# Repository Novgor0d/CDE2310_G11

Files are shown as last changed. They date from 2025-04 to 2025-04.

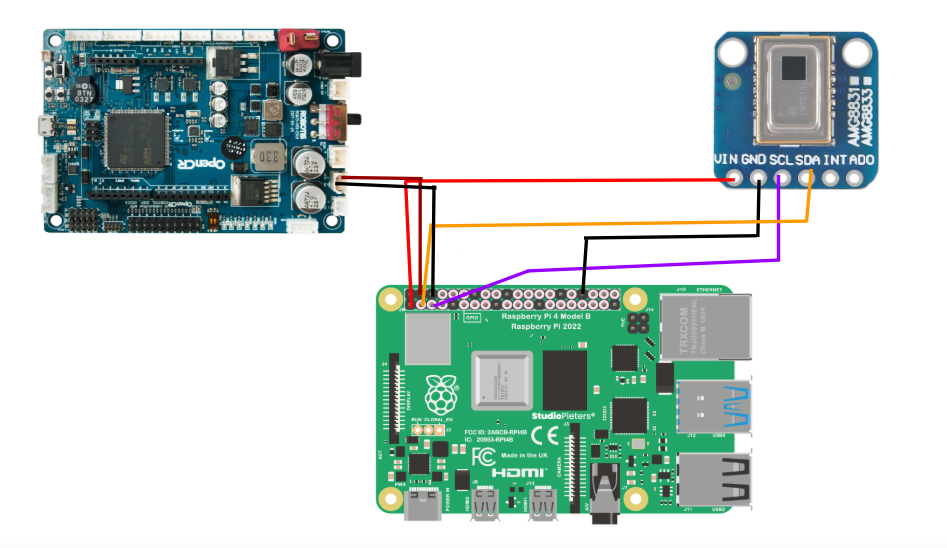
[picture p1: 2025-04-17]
Electrical Subsystem/Circuit_Diagram_AMG8833.png

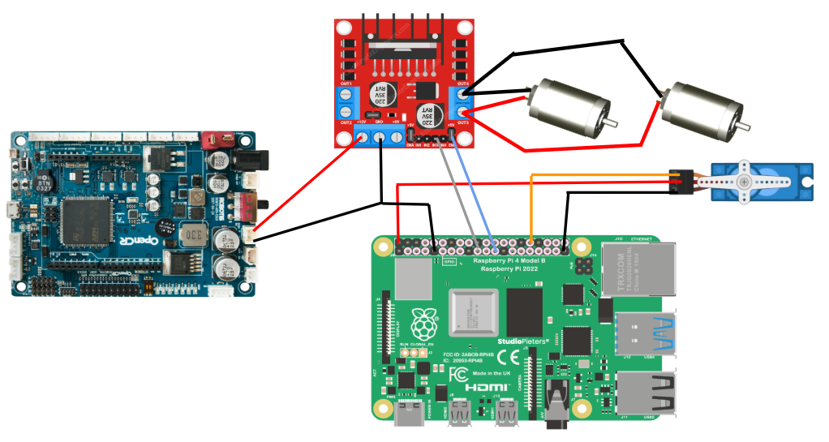
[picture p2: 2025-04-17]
Electrical Subsystem/Circuit_Diagram_Flywheel.png

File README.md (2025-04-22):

##  Project Overview

This repository contains the project details for **CDE2310 AY24/25**.

The contents within the following folders can be used to **replicate the project**:
- `Software`
- `Electrical Subsystem`
- `Mechanical Subsystem`

The **mission details**, along with all **conditions and constraints**, are provided in the `Requirement Specifications` document.
The **User Manual** and **Testing Documentation** contain detailed information about the **robot's design** and **how its functionality can be tested** prior to mission execution.

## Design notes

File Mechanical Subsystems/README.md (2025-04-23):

## Mechanical Subsystem

This document outlines the **complete design, fabrication, and assembly process** for our autonomous ping pong ball launcher mounted on the TurtleBot3 Burger. The system is designed to detect a heat source, navigate autonomously, and fire a ping pong ball vertically using a dual-flywheel launch mechanism. It includes detailed breakdowns of parts, fabrication methods, performance calculations, and step-by-step assembly instructions to ensure clarity and reproducibility.

**_All the items that have been mentioned in this document refer directly to the file name._**

## Files and their description under Mechananical Subsystems

**Reload Tube Folder:**
- Joint2: attatches 18cm pipe to the launcher 
- Joint: attatches 15cm pipe to the 18cm pipe 
- Reload Tubes assem: the entire assembly file with pipes and joints
- Tube 18cm: attaches to the launcher directly using a press-fit joint
- Tube 15cm
- Tubes holder: Attaches to turtlebot for holding the 18cm tube 

**Launcher Folder:**
- DC motor & servo platform: Attaches DC motors and servo to the turtlebot 
- DC motor gear: 30 teeth 
- JGB37-520 left assem: assembly file with motor
- JGB37-520 left bracket  
- JGB37-520 right assem: assembly file with motor  
- JGB37-520 right bracket  
- SG90 servo assem (rack and pinion)  
- SG90 servo bracket (rack and pinion)  
- ball platform - Holds the ball and has the rack (15 teeth)
- flywheel - File has the flywheel plus the gear (12 teeth) 
- launcher + reload tubes assem  
- launcher  
- pinion gear (rack and pinion): 29 teeth

**Turtlebot Assembly files:**
- Turtlebot Assembly:- Base turtlebot burger
- Turtlebot & Launcher Mechanism Assembly: Final Turtlebot Burger assembly with the launcher and the ball feeder system.

## 3D Printing
CAD files can be saved as STL files to 3D Print.

**Parts to be printed:**
- Launcher 
- JGB37-520 left bracket
- JGB37-520 right bracket  
- SG90 Servo Bracket 
- Ball Platform
- Joint 2
- Joint
- Tubes Holder
- 2X Flywheel (with integrated gear teeth)
- SG90 servo Bracket (heat sensor)

**Specifications for 3D Printing:**
- Infill: 15%
- Material: PLA 

## Laser Cut:
Using a 5mm acrylic sheet the following needs to be laser cut

_Parts to be Laser cut:_
- 2X DC Motor gear 
- Pinion Gear 
- DC Motor and Servo Platform

## Assembly Plan

**Assembly Step 1: SG90 Servo + Heat Sensor Mounting**
- Mount the SG90 servo to the front of the second level using M4×15 screws.
- Attach the sensor bracket to the servo horn using M2×10 screws.
- Fix the AMG8833 heat sensor onto the bracket using M2×10 screws.

**Assembly Step 2: Mount Pinion and Attach Servo Platform**
- Attach the pinion gear to the output shaft of the SG90 servo.
- Mount the servo onto the platform bracket using M2×15 screws.
- Fix the entire servo and motor platform onto the top layer using M3×15 screws through the holes aligned with the hex standoffs.

**Assembly Step 3: Mount Flywheel Launcher Assembly**
- Mount the JGB37-520 motors onto the launcher platform using M2×15 and M4×15 screws.
- Attach the 30-tooth motor gear to the motor shaft.
- Wrap each flywheel with 8 rubber bands each to improve traction.
- Slide the 3D printed shaft through the flywheel and secure it so the 12-tooth flywheel gear meshes precisely with the motor gear (gear ratio 5:2).
- Insert the ball holder platform from above
- Extend the third platform layer by attaching M3×20 hex standoffs to the existing mounting holes.
- Secure the entire launcher assembly onto the TurtleBot chassis using M4X15 and M3X15 screws through the designated mounting holes, aligning the pinion (29T) on the servo with the rack (15T) for accurate engagement.

**Assembly Step 4: Ball Feeder Pipe Installation**
- Mount the pipe support bracket to the TurtleBot platform using M2×20 screws.
- Press-fit the 15 cm PVC pipe into the 3D printed 90° elbow joint.
- Connect the 15 cm pipe to the 18 cm PVC pipe using the same elbow joint.
- Press-fit the other end of the 18 cm pipe into the 3D printed joint2,
- Press-fit joint2 onto the launcher housing and finally, rest the assembled tube system onto the tube holder.

## Launcher Calculations 

**Specifications & Assumptions:**
- Mass of Ping Pong Ball: 2.7 g (0.0027 kg)
- Target Launch Height: 1.5 m
- Flywheel Diameter: 5 cm (0.025 m radius)
- Motor Used: JGB37-520 (nominal no-load speed ~960 RPM)
- Gear Ratio: 30:12 (2.5× step-up)

**Required Launch Velocity:**
v = √(2gh) = √(2 × 9.81 × 1.5) ≈ 5.42 m/s

**Required Flywheel RPM:**
ω = v / r = 5.42 / 0.025 = 216.8 rad/s
RPM = (216.8 × 60) / (2π) ≈ 2072 RPM

**Achieved Flywheel RPM:**
With gear ratio of 2.5× (30 teeth : 12 teeth):
Achieved RPM = 960 RPM (motor) × 2.5 (gear ratio) = 2400 RPM

Our flywheel system achieves an RPM of 2400, which exceeds the required 2072 RPM. This confirms our system can successfully launch the ping pong ball to at least 1.5 meters vertically, satisfying the project requirements  with a performance buffer that accounts for real-world factors such as air resistance and energy losses from friction.

## Mechanical and Assembly Recommendations
- Ensure motor shafts and flywheels are securely fastened to prevent slippage at high RPMs.
- Align gears and flywheels properly to minimize vibration during operation.
- Test with gradual motor ramp-up to check for imbalance or resonance.
- Ensure the PVC ball guide path has minimal friction and doesn’t interfere with launch direction.

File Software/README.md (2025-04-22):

# **Thermal Detection and Autonomous Exploration System**
## **Overview**
This repository contains the software framework for a robotic system capable of detecting thermal sources while performing autonomous exploration of an unknown environment. The system is built on ROS2 and meant for deployement on Raspberry Pi. It maps the surroundings using SLAM, detects heat signatures, and deploys a flare mechanism.

## **Key Features**
- **Autonomous frontier-based exploration:** Uses a frontier exploration algorithm to autonomously navigate towards unexplored regions.
- **Thermal Source Detection:** Detects heat sources based on certain temperature thresholds.
- **Motorized flare deployment:** Fires a flare to indicate successful detection of a heat source, using a flywheel and servo-based system.
- **Data Logging**: Provides detailed logging of system status, sensor data, and actions for debugging and performance monitoring.
- **Full ROS2 Humble compatibility**

## **System Architecture**
The software stack is divided across two platforms:
  - **Remote PC (Main Control Node):** Runs SLAM, Nav2 Stack, RViz visualisation, and the exploration node.
  - **Raspberry Pi (Onboard Robot):** Handles robot bring-up, thermal sensing, and flare deployment mechanisms.
  
## **Prerequisites**
- Ubuntu 22.04 (recommended)
- ROS2 Humble
- ROS2 Packages: nav_msgs, geometry_msgs, action_msgs

  [( Install ROS2 packages and Turtlebot3 here )](https://emanual.robotis.com/docs/en/platform/turtlebot3/sbc_setup/#sbc-setup)
  
  Add the following line to the `.bashrc` file in the root directory of the Remote PC and RPi
   ```bash
   export TURTLEBOT3_MODEL=burger
    ```
  Reload the `.bashrc` file
     ```bash
   source ~/.bashrc
    ```

- Python 3.10+
- Python libraries:
  - `numpy`  
    Install with:  
    ```bash
    pip install numpy
    ```
  - `adafruit-circuitpython-amg88xx`  
    For using amg8833 sensor with Raspberry Pi. Install with:  
    ```bash
    pip install adafruit-circuitpython-amg88xx
    ```
  - `adafruit-blinka`  
    Required for `busio` and `board` on Raspberry Pi. Install with:  
    ```bash
    pip install adafruit-blinka
    ```
## **Installation and Setup**
1. **Create the ROS2 workspace:**
```bash
mkdir -p ~/ros2_ws/src
```
2. **Clone the repository:**

  (On Remote PC)
```bash
cd ~/ros2_ws/src
git clone https://github.com/Novgor0d/CDE2310_G11.git
cd CDE2310_G11/Software/src
cp -r * ~/ros2_ws/src/
rm -rf ~/ros2_ws/src/CDE2310_G11
# Copy the 'src' directory from the local machine's ros2_ws to the Raspberry Pi's ros2_ws/src directory
scp -r ~/ros2_ws/src pi@rpi_ip_address:/home/pi/ros2_ws/src
# Replace the username and ip address with your RPi's
rm -rf ~/ros2_ws/src/thermal_explorer
rm -rf ~/ros2_ws/src/fire_flare
```
  (On RPi)
```bash
# These commands are to be run after the 'src' directory has been copied over from the remote PC to the RPi
cd ~/ros2_ws/src
rm -rf ~/ros2_ws/src/custom_explorer
rm -rf ~/ros2_ws/src/robot_config
```
The rm commands are used to clean up the workspace by removing nested or redundant directories after extracting the necessary packages for remote PC and RPi, ensuring a flat and organized structure in ~/ros2_ws/src.

3. **Install dependencies and build the workspace:**
```bash
cd ~/ros2_ws
rosdep install --from-paths src --ignore-src -r -y
colcon build
```
4. **Source the workspace:**
```bash
source install/setup.bash
```
## **Running the System**
### ***On Remote PC:***
Run the following commands in separate terminal windows:
1. **Start RViz2 for visualization:**
```bash
ros2 run rviz2 rviz2 -d $(ros2 pkg prefix nav2_bringup)/share/nav2_bringup/rviz/nav2_default_view.rviz
```
2. **Launch SLAM:**
```bash
ros2 launch slam_toolbox online_async_launch.py
```
3. **Use Custom Navigation Parameters:**
   
This system uses a customized nav2_params.yaml file located at: robot_config/config/nav2_params.yaml
```bash
ros2 launch robot_config nav2_launch.py
```
This step ensures that all Nav2 nodes (e.g., planner, controller, recovery behaviours) run with the tuned parameters specific to this project. These parameters can be adjusted as per requirement.

4. **Run the custom exploration node:**
```bash
ros2 run custom_explorer explorer
```
### **On Raspberry Pi:**
Run the following commands in separate terminal windows:
1. **Launch TurtleBot3 bringup:**
```bash
ros2 launch turtlebot3_bringup robot.launch.py
```
2. **Start the thermal detection node:**
```bash
ros2 run thermal_explorer thermal
```
3. **Run the flare firing mechanism:**
```bash
ros2 run fire_flare motor
```
## **Simulating in Gazebo:**
To simulate the navigation in a virtual environment, run the following commands in separate terminals:
1. **Launch the TurtleBot3 in a Gazebo simulation world:**
```bash
ros2 launch turtlebot3_gazebo turtlebot3_world.launch.py
```
2. **Launch SLAM with simulation time enabled:**
```bash
ros2 launch slam_toolbox online_async_launch.py use_sim_time:=True
```
3. **Launch Nav2 stack with simulation time enabled:**
```bash
ros2 launch robot_config nav2_launch.py use_sim_time:=True
```
4. **Run the custom exploration node in the simulation:**
```bash
ros2 run custom_explorer explorer
```

## **System Functionality**
### **Thermal Detection and Flare Firing**
Upon initialization, the system continuously scans the environment using the thermal sensor. When a heat source (e.g., fire) is detected, the robot navigates towards the source and fires a flare to indicate the detection. The detection and flare firing are performed based on a predefined temperature threshold, which can be configured to suit various use cases.

### **Autonomous Exploration**
The system employs a frontier exploration algorithm that identifies unexplored areas (frontiers) in the environment. The robot autonomously navigates towards these regions to gather more data, expanding its knowledge of the environment. The system dynamically switches between frontier-based exploration and random exploration after specified time intervals.

### **ROS2 Communication**
The system utilizes ROS2 for communication between the various components:

**Published Topics:**
  - /fire_flare ([Bool]): Indicates when the robot detects a thermal source and fires a flare.
  - /cmd_vel ([geometry_msgs/msg/Twist]): Command velocity for controlling robot movement.
  - /goal_pose ([geometry_msgs/msg/PoseStamped]): The target position for the robot (e.g., towards a detected heat source or frontier).

**Subscribed Topics:**
   - /odom ([nav_msgs/msg/Odometry]): Odometry data used for robot localization.
   - /map ([nav_msgs/msg/OccupancyGrid]): The map of the environment for exploration and frontier detection.

## Testing and Validation
The system has been tested both in simulated environments (Gazebo) and with real-world hardware. The modular nature of the system ensures that individual components can be tested in isolation for reliability.

The folder **/Test** contains verification scripts for hardware-level functionality of the thermal detection and flare deployment system used in the project.

### **Contents**

**AMG8833_test.py**
- Sweeps a servo across predefined angles.
- Uses the AMG8833 thermal camera to detect heat signatures above a defined threshold.
- if a high heat count is detected, triggers a flare firing sequence by executing Motor_Test.py

**Motor_Test.py**
- Activates a flywheel mechanism and sequentially fires three flares using a servo reload action.
- Includes controlled delays for flywheel spin-up and reload timing.

**servo_reset.py**
- Simple utility script to reset the servo to a neutral (0-degree) position after firing or testing.

### Usage

Ensure you have the necessary hardware connected (thermal sensor, servo, flywheel mechanism), then run the scripts on RPi using
```python
python3 [file_name].py
```

## References
This project was developed with guidance and inspiration from the following sources:
  - [Nav2 Documentation](https://docs.nav2.org/)
  - [Automatic Addison – ROS 2 Navigation Tuning Guide (Nav2)](https://automaticaddison.com/ros-2-navigation-tuning-guide-nav2/)
  - [AutoFrontierSearch (ROS2 - Humble)](https://github.com/Nyanziba/AutoFrontierSearch_ros2-humble/tree/main) – Frontier exploration logic adapted and modified for our use.

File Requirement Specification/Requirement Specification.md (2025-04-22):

#  IR-Heat Detection & Projectile Launcher System for TurtleBot3 Burger (Raspberry Pi 4)

##  Mission Objective

Design and build an **IR (heat) detection module** with an integrated **projectile launcher** for a **TurtleBot3 Burger** running on **Raspberry Pi 4**, capable of completing the following tasks within a single mission:

---

##  Maze Navigation Requirements

1. The TurtleBot must **autonomously navigate a maze** no larger than **5m × 5m**.
2. Maze walls are under **1 meter** in height.

---

##  IR Detection Objectives

1. Within the maze, the robot must locate a **designated heat signature zone**, marked by an **IR-lamp** in an enclosed area that is **randomly placed**.
2. The TurtleBot must also identify **three "Target" objects** (biscuit tins), each with an **infrared heat signature ("Hot target")**.
3. Each hot target has a **vertical positional marker** placed **1.5m above** it.

---

##  Launching Requirements

- The robot must:
  - **Detect** the hot target.
  - **Orient** its position accordingly.
  - **Aim and fire** at the vertical positional marker.
  - Launch a **minimum of 3 ping pong balls** in the following **timing pattern**:  
    **2s → 4s → 2s** intervals between shots.

---

##  Conditions & Constraints

1. All targets are placed **on the floor**.
2. There is **only one elevation zone** (non-critical) located in the **bonus zone**.
3. The projectile must be a **standard-sized ping pong ball**.
4. The **terminal height of the projectile must exceed the height of the maze walls**.
5. The **ping pong ball must not hit the wall or ceiling** of the surrounding room.

---

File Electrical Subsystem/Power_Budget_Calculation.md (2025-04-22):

##  Power Budget Calculations

### **Assumptions**
- **Battery efficiency**: 80%
- **Boot-up time**: 20 seconds  
- **Stand-by time**: 50 seconds  
- **Operation time**: 30 seconds

---

### **Calculation**
(8.4 × 20) + (5.9 × 50) + (13 × 30) + (10.22 × T) = 11.1 × 1.8 × 3600 × 0.8 => T = 92.3 minutes

This means after one complete charge, the **TurtleBot** is expected to run for approximately **92.3 minutes**.

---

**_Note: Please refer to `Power_Budget_Table.png` for the power distribution of each component, which has been used in the above calculations._**

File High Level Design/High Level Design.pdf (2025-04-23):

## High Level Design

Scope:
The robot is equipped to navigate through the maze, detect heat sources and shoot ping-pong balls upon detection, with a time interval of 2s-4s-2s.

Architecture Diagram:
The following diagram illustrates how the various components of the system interact with each other.

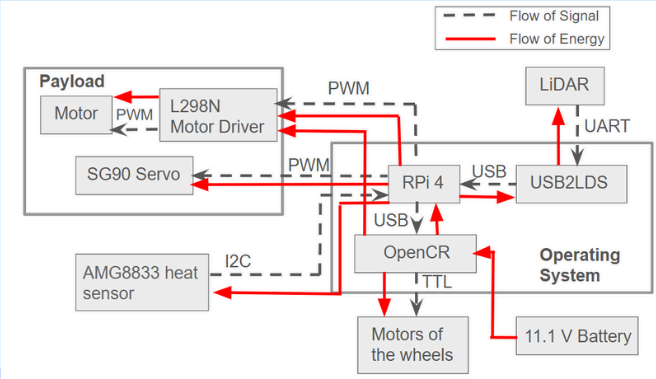
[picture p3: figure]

Component Description:

Item No. | Qty | Part Name
1 | 1 | S90 servo for heat sensor
2 | 1 | AMG8833 sensor
3 | 1 | Ball holder
4 | 2 | Flywheel motor
5 | 2 | Flywheel
6 | 1 | S90 servo for rack and pinion
7 | 1 | Rack and pinion
8 | 1 | Pipe support
9 | 1 | Sensor servo holder
10 | 1 | Acrylic Holder for Launcher
11 | 1 | Weight
12 | 1 | Turtlebot3 burger

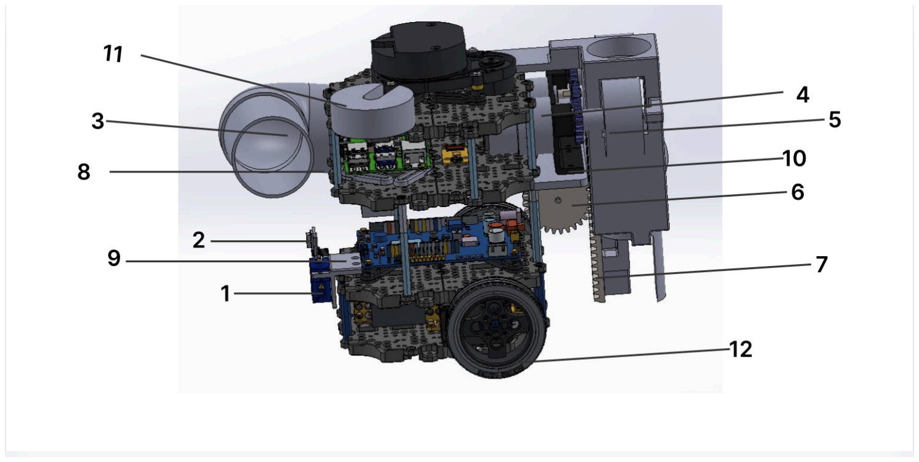
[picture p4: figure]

+

The map created by the lidar along with the odometry reading helps in updating the local and global costmap, along with giving the position of the robot on the map. The pipes are used to store the ping-pong balls. The AMG8833 heat sensor provides a 8x8 array of temperatures, which is used to scan for heat sources. Upon detection of heat sources, the rack and pinion along with the flywheel is activated, which shoots the ping-pong balls. The weight is used to balance out the weight of the motors and launcher, on the other side of the bot.

Data/Control Flow:
The flowchart below shows the logic diagram for heat detection:

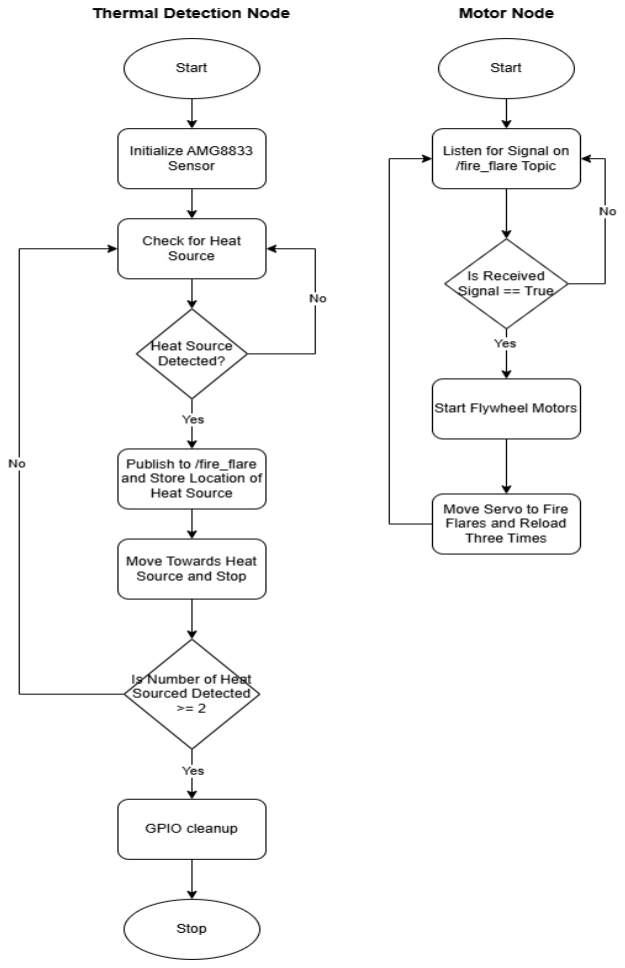
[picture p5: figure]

Fig: Logic diagram for heat detection

The flowchart below represent the logic diagram for navigation:

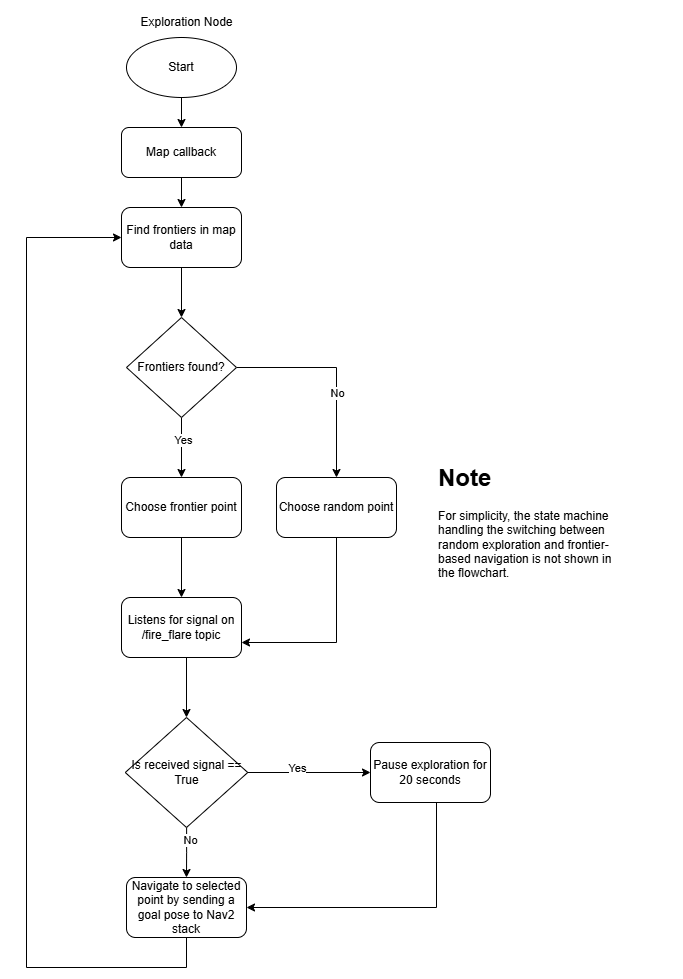
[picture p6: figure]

Fig: Logic diagram for navigation.

Design Consideration:

| List | Specifications | Notes
Turtlebot | Dimensions (mm) (LxWxH) | Turtlebot3 & Launcher: 293x262x212
| Weight (kg) | Launcher: 0.924 Turtlebot: 1.51 Counter-weight: 0.2 Total weight: 2.634
| Wheel Base (mm) | 80.66 | From center of DYNAMIXEL to the center of ball caster
| DC Motor | 2x JGB37-520
| Servo Motor | 2x SG90
Payload | Dimensions (mm) (LxWxH) | 40 x 40 x 40 | Ping Pong Ball
| Weight (kg) | Ping Pong: 0.0027 Total: 0.0243 | 9 Ping Pong Ball
System | Battery Capacity | 1800 mAh
| Expected Operating Time | 92.3 min
| Communication Interface | GPIO,PWM,I2C,UART,USB, TTL, TCP

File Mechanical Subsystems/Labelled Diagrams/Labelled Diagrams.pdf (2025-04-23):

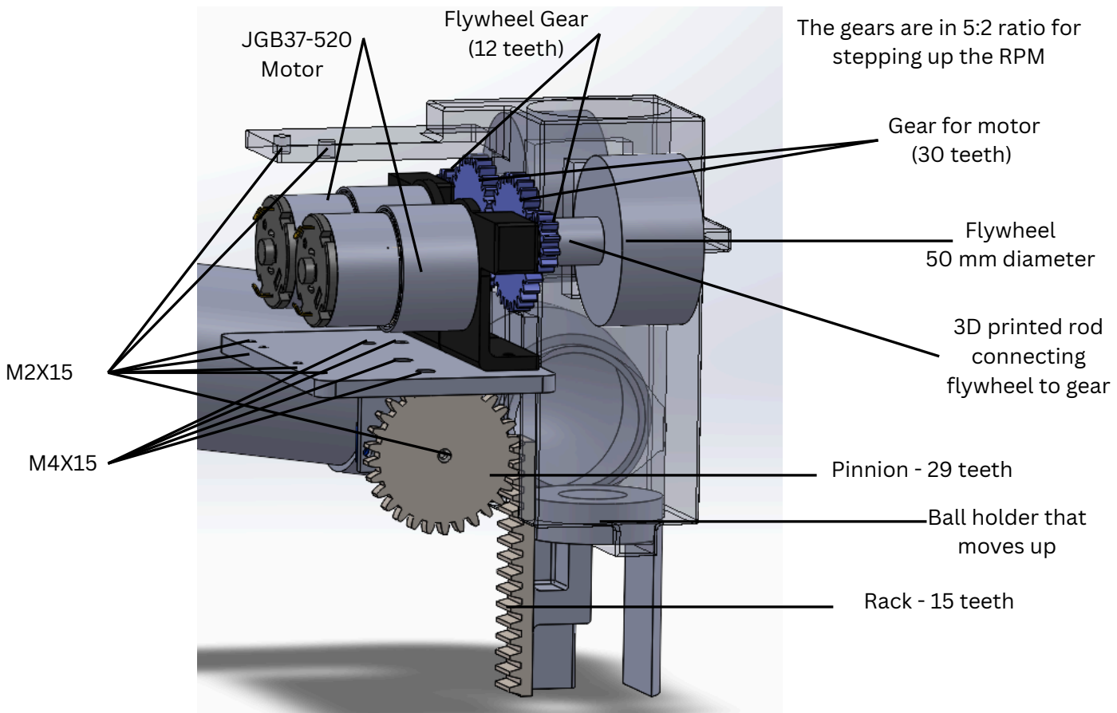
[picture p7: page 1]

Pinnion - 29 teeth

Rack - 15 teeth

Flywheel
50 mm diameter

JGB37-520
Motor

M2X15

M4X15

Gear for motor
(30 teeth)

Ball holder that
moves up

3D printed rod
connecting
flywheel to gear

Flywheel Gear
(12 teeth)

The gears are in 5:2 ratio for stepping up the RPM

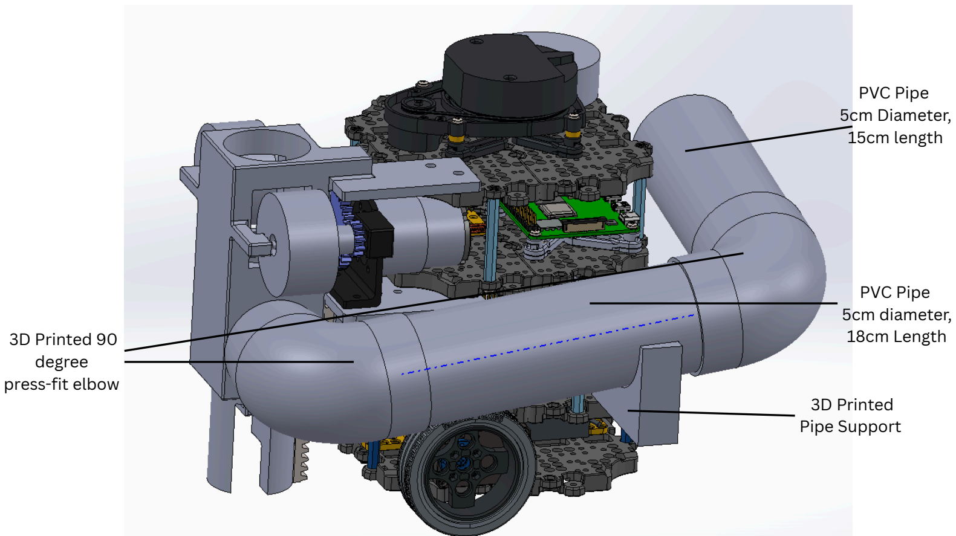
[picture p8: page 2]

PVC Pipe
5cm diameter,
18cm Length

3D Prin

ted
Pipe Support

3D Prin

ted 90
degree
press-fit elbo

w

PVC Pipe
5cm Diameter,
15cm length

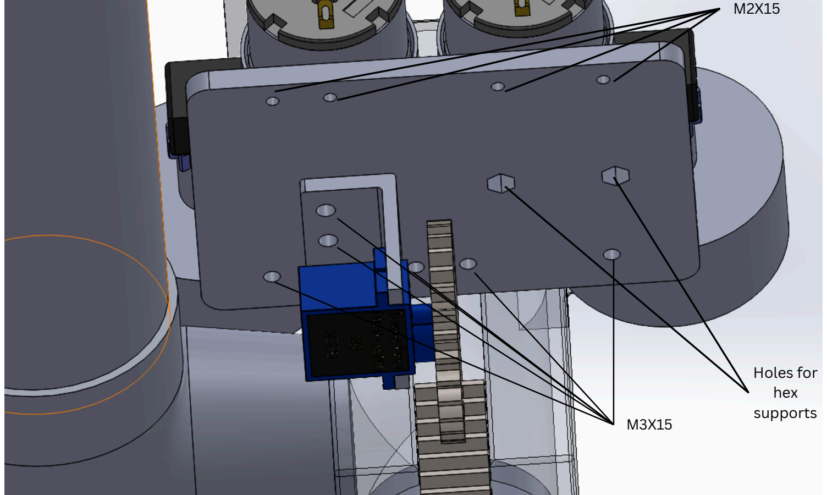
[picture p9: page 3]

M2X15

Holes for
hex
supports M3X15

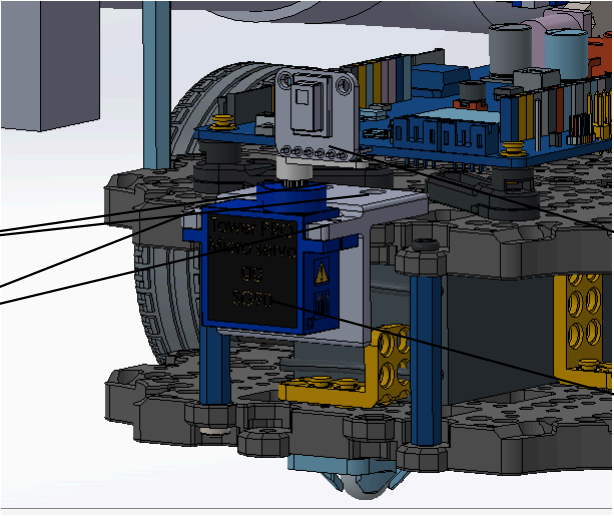
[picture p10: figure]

SG90 Serv

o

AMG8833
Heat Sensor

M4X15

M2X10

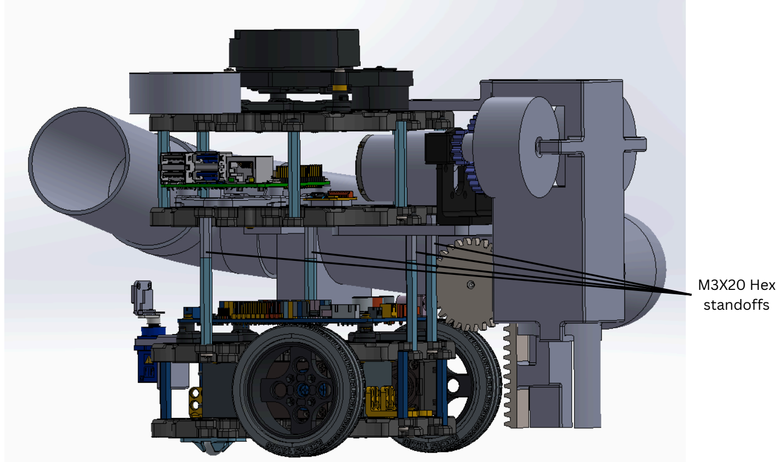
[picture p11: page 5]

M3X20 Hex
standoffs

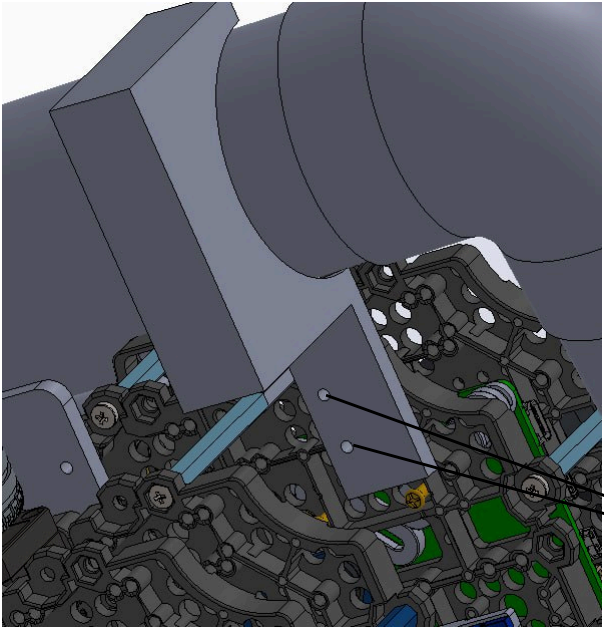
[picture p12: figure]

M2X20

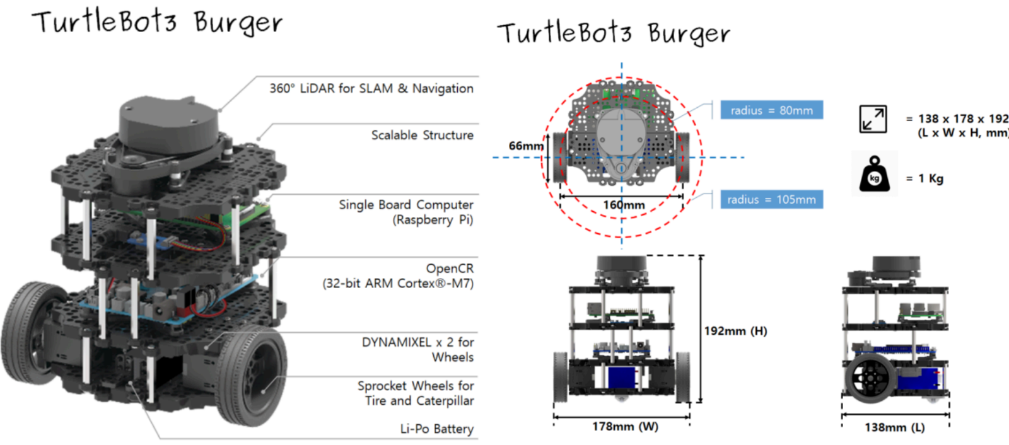
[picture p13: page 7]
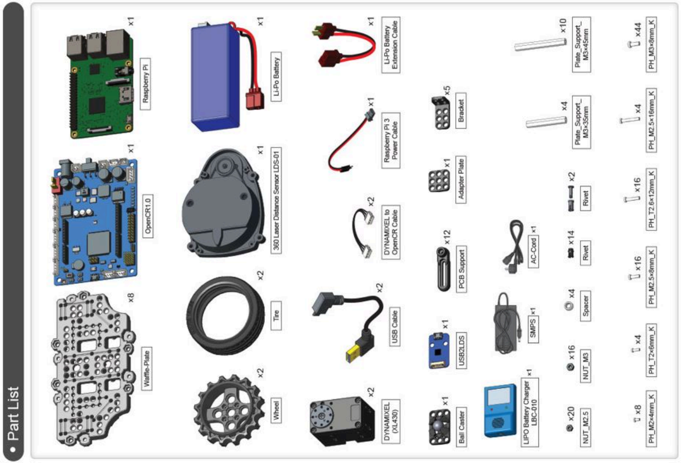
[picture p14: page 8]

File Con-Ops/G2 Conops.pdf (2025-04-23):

Problem Description
The mission involves designing and building a TurtleBot3 Burger system equipped with a IR (heat) detection module and a projectile launcher capable of autonomously navigating a 5m x 5m maze with walls under 1m in height. Within the maze, the robot must locate a designated heat signature zone marked by an IR lamp enclosed in a randomly placed space and identify three "hot targets" — biscuit tins emitting infrared heat and marked with vertical position indicators 1.5m above them. Upon locating a hot target, the robot must orient itself, aim, and fire three ping pong balls at the vertical marker in a specified 2s–4s–2s timing

sequence.

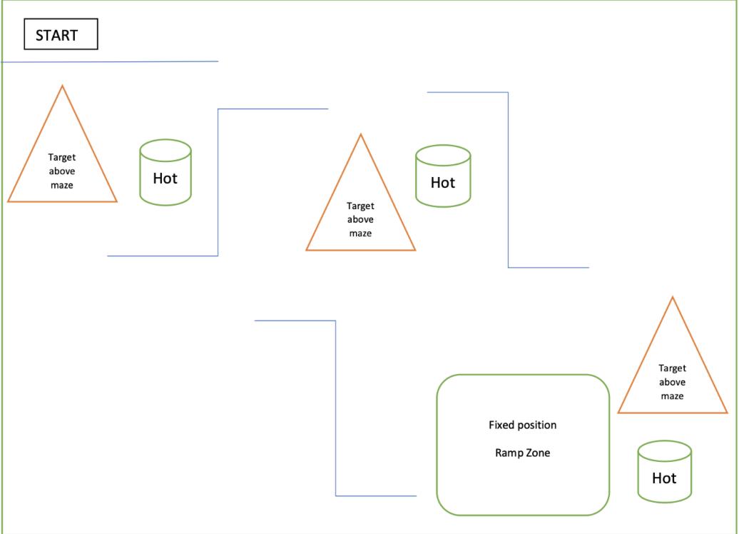
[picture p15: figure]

Figure 1: Mission Layout

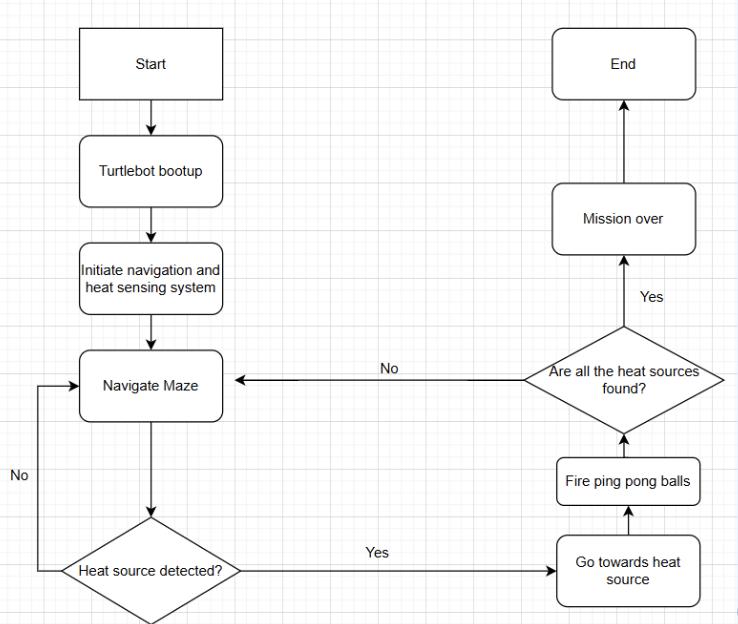
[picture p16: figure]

Figure 2: General Con-Ops Overview

Stakeholder Requirements | Project Deliverables
Traverse map autonomously | Implement mapping techniques to generate real time map of maze
Avoid obstacles | Develop capability for obstacle avoidance and navigation
Detect Heat source | Detect heat readings and trigger launcher when above threshold
Fire Flares above 1m | Generate enough power to fire ball above 1m
Fire at interval | Incorporate firing timing at 2-4-2 intervals
Stakeholder Requirements | Functional Requirements
Traverse map autonomously | Using SLAM incorporate frontier exploration and path planning algorithm to continuously update and refine map during exploration
Avoid obstacles | Utilise sensors and lidar to detect obstacles and navigate around them

Detect Heat source | Using heat sensor set threshold and create code such that when threshold is hit, launch mechanism triggers
Fire Flares above 1m | Use flywheel mechanism ,rack and pinion system to load balls into flywheel mechanism
Fire at interval | Using servo adjust speed at which balls are loaded into the flywheel
Constraints | Description
Cost | 80 Dollar budget
Power | Operate within constraints of power source
Sensor | Limited by cost and availability
Processing power and memory | Limited due to Rpi, affects algorithm efficiency
Size | Fit within walls and passages of the maze

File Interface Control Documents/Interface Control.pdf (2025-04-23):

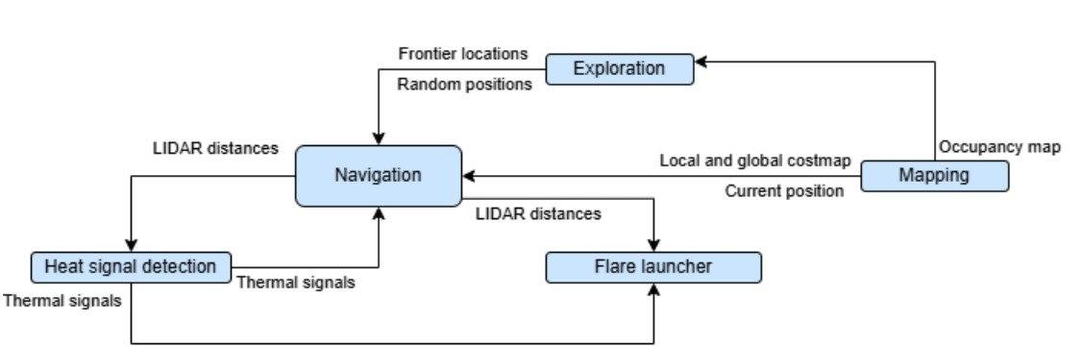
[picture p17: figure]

Interface Control Flowchart

The flowchart illustrates the software architecture and data flow in the autonomous Turtlebot system designed for IR-based search and targeting. The core of the system is the Navigation module, which receives frontier locations or random positions from the Exploration module to guide the robot through the environment. The Mapping module continuously updates the local and global costmap and provides the current position based on the occupancy map, feeding this information to the Navigation module for real-time decision-making. Simultaneously, LiDAR distances are used by both the Navigation module and the Heat Signal Detection unit to localize and identify thermal targets. Upon detecting valid thermal signals, the Heat Signal Detection module relays data to the Flare Launcher, which uses both thermal and LiDAR inputs to determine when and where to launch a flare. This integrated loop allows for autonomous mapping, exploration, and accurate response to heat-based targets within a complex maze environment.

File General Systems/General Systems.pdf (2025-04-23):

Autonomous Navigation – SLAM, Frontier Exploration & A* Path Planning

At the core of the robot’s autonomous navigation system is a 2D LiDAR sensor, which continuously scans its surroundings to generate a real-time occupancy grid map via SLAM (Simultaneous Localization and Mapping). This dynamic map serves as the foundation for both exploration and navigation. The robot employs a frontier-based exploration strategy, which identifies boundaries between explored and unexplored space ("frontiers")and prioritizes movement toward these regions to maximize map coverage efficiently. Once a frontier goal is selected, the A* path planning algorithm is used to compute an optimal route through free space, balancing path length and obstacle avoidance. This high-level planner interfaces with local control modules to generate velocity commands, enabling the robot to maneuver safely around static walls and dynamic obstacles while progressing toward its mission objectives. The integration of SLAM, frontier detection, and A* ensures reliable, efficient, and intelligent navigation within unknown and complex maze environments.

Launcher Mechanism – Flywheel System

This system operates by rapidly spinning a pair of opposing wheels using JGB37-250 motors, generating sufficient tangential velocity to propel lightweight projectiles such as ping pong balls. When a projectile is fed into the flywheel gap, frictional contact with the rotating surfaces accelerates it forward at high speeds.We make use of a gear train to increase RPM with the bigger gear connected to the motor and the smaller gear connected to the flywheel axle. This is paired together with our ball loading system to create our flare mechanism.

Rack and Pinion - Ball Loading System

To support automated and repeatable firing, the robot integrates a rack and pinion-based loading mechanism. This system uses a linear actuator where rotational motion from a servo-driven pinion gear is converted into linear displacement of the rack. Each stroke of the rack pushes a single projectile from a pipe into the flywheel launching chamber. This mechanical design ensures consistent alignment and loading of the projectile, minimizing jams while enabling controlled reloading cycles synchronized with the firing sequence. The servo timing was adjusted using code to ensure it loads the balls at 2-4-2 intervals. The pipe rests on a pipe holder and the pipe is at an angle such that the gravitational force causes the balls to roll into the holding area before it is fed into the flywheel.

Heat Detection

The AMG8833 heat sensor creates an 8x8 array of temperatures. When the temperature value and temperature count exceeds a threshold, the launching mechanism is activated.

Power Consumption, Operation time and battery specification

Battery specification: 11.1V, 1800 mAh
Total time for which the system can operate: 92.3 min

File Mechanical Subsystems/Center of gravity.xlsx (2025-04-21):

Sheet: Turtlebot
Part Name |  | CG Position (mm) |  |  | remarks
 | mass (g) | x | y | z
Left wheel | 83.5 | 32.77 | 20.25 | 88.99
Right Wheel | 83.5 | 36.77 | 20.25 | -67.45
Raspberry Pi | 47 | 99.26 | 103.84 | 2.74
OpenCR | 64 | 62.05 | 55.89 | 11.69
Left Motor | 113 | 44.52 | 20.52 | 62.94
Right Motor | 113 | 48.52 | 19.98 | -42.41
Battery | 139 | 72.43 | 19.75 | 10.22
LiDAR | 127 | 67.79 | 139.84 | 10.38
PCB | 64 | 53.76 | 94.07 | 12.02
Ball Caster | 8 | 117.77 | -6.22 | 10.25
Waffle Plates First Floor | 79.5 | 68.77 | 2.16 | 10.26 | bottom plate
Waffle Plates Second Floor | 79.5 | 68.77 | 39.61 | 10.26
Waffle Plates Third Floor | 79.5 | 68.77 | 86.71 | 10.26
Waffle Plates Fourth Floor | 79.5 | 68.77 | 133.71 | 10.26 | top plate
Plate support 1a | 25 | 4.77 | 21 | -13.73
Plate support 1b | 25 | 4.77 | 18.8 | 34.27
Plate support 1c | 25 | 132.77 | 20.95 | 34.25
Plate support 1d | 25 | 132.77 | 18.75 | -13.75
Plate support 2a | 25 | 4.77 | 61.1 | -1.73
Plate support 2b | 25 | 92.77 | 63.25 | -53.75
Plate support 2c | 25 | 92.77 | 61.05 | 74.25
Plate support 2d | 25 | 4.77 | 63.3 | 22.27
Plate support 3a | 25 | 44.77 | 110.21 | 74.27
Plate support 3b | 25 | 4.77 | 108.01 | 34.27
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

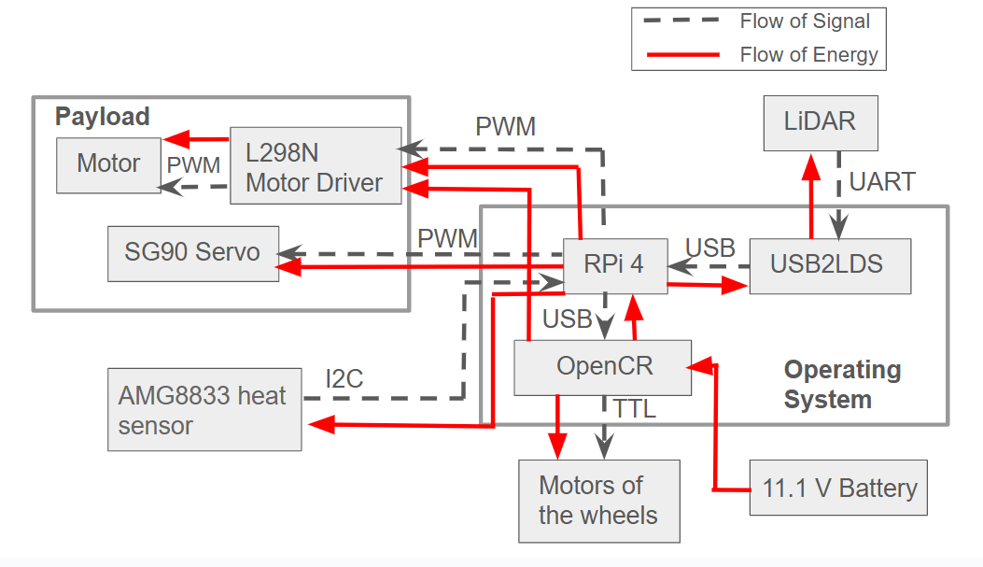
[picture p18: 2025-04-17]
Electrical Subsystem/Electronic_Architecture_Diagram.png

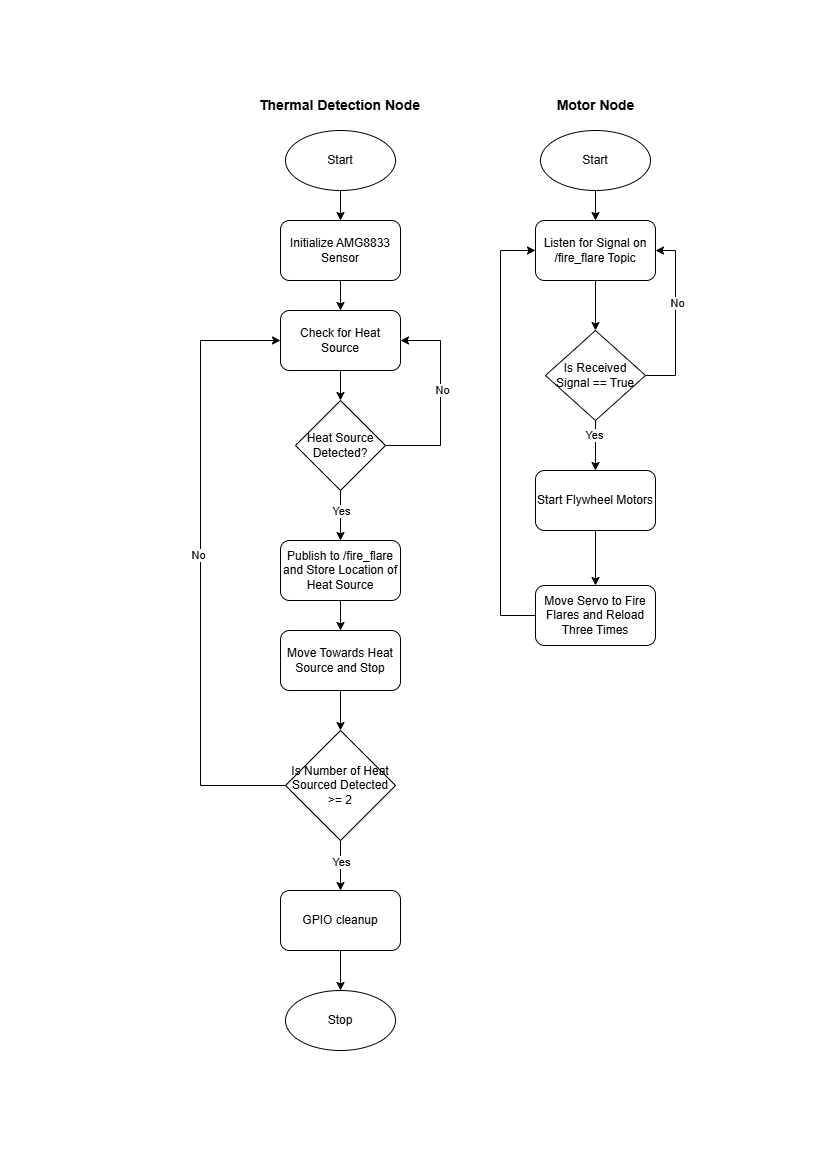
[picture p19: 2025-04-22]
Software/RPi_fowchart_high_level.png

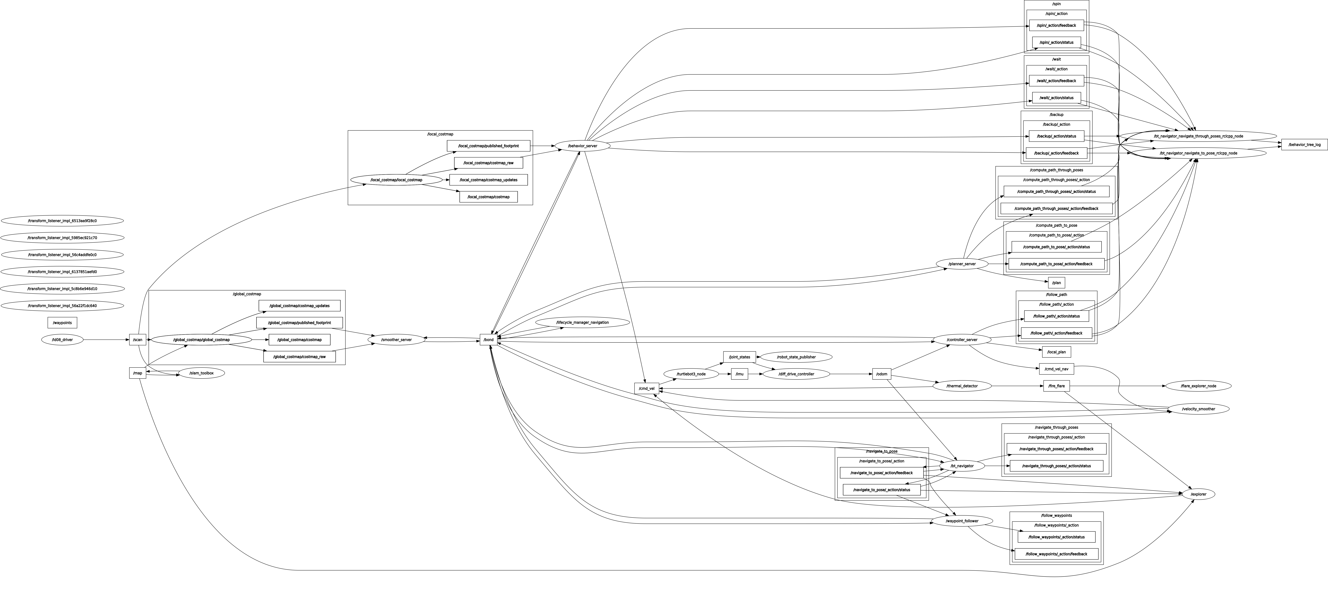
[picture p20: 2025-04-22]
Software/rqt_graph.png

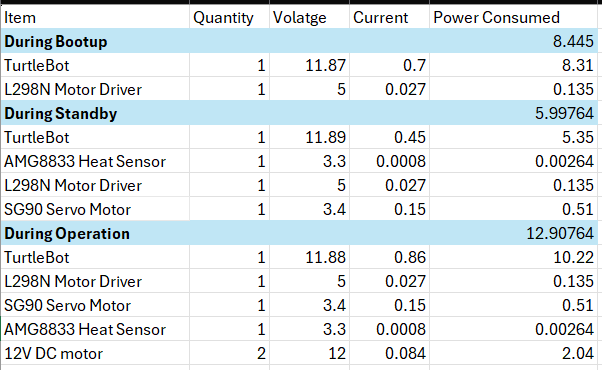
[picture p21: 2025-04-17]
Electrical Subsystem/Power_Budget_Table.png

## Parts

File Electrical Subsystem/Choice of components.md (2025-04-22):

##  Choice of Components

### 1. **AMG8833 Temperature Sensor**
- Provides an **8×8 grid** of temperature points.
- **Low power consumption**.
- Temperature range: **-20°C to 80°C**.
- Frame rate: **10 frames/sec**.
- Has a built-in **ADC**, eliminating the need for an external ADC on the Raspberry Pi.
-  *Chosen for simple and budget-friendly heat detection.*

---

### 2. **12V Motors (JGB37-520)**
- Two 12V motors are used to power the **flywheels**.

---

### 3. **L298N Motor Driver**
- Used to control the two 12V flywheel motors.

---

### 4. **SG90 Servo Motor**
- Integrated into the **rack and pinion mechanism**.
- Pushes the platform holding the ball up to the flywheel.

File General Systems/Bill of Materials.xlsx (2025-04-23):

S/N | Item | Quantity | Price | Remarks
1 | 3D Printing Parts | 11 | $40
2 | Laser Cut Parts | 4 | $9
3 | PVC Pipe Outer Diameter 50mm | 2 | $2.20
4 | AMG8833 Heat Sensor | 1 | $30 | Borrowed from Lab
5 | JGB37-520 DC Motor | 2 | $24 | Borrowed from Lab
6 | SG90 Servo | 2 | $12 | Borrowed from Lab
7 | L298N Motor Driver | 1 | $2.29 | Borrowed from Lab
 |  | Total | $119.49

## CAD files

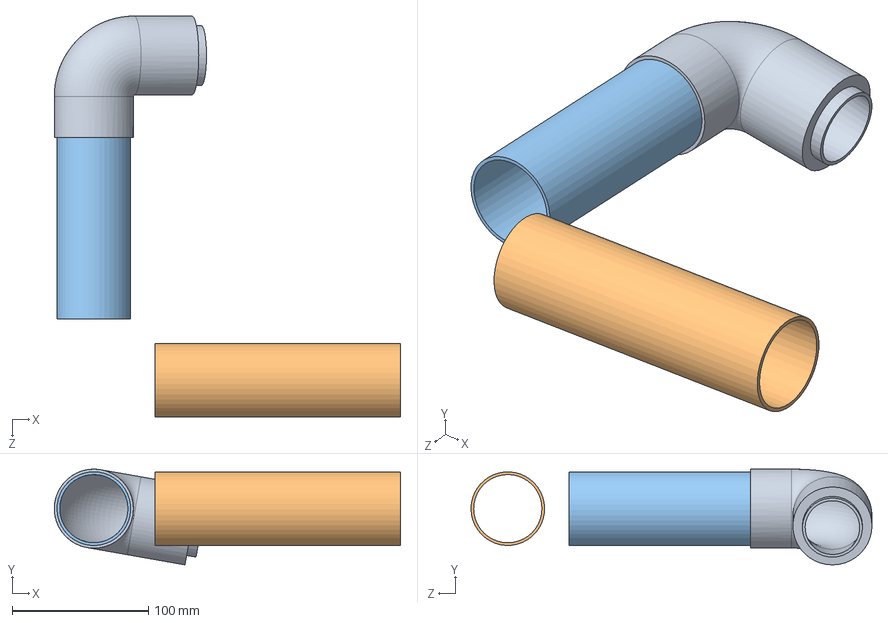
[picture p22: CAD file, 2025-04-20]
Mechanical Subsystems/Reload Tubes/reload tubes assem.SLDASM
254.0 x 70.2 x 294.0 mm
tube 15cm
tube 18cm
joint 2

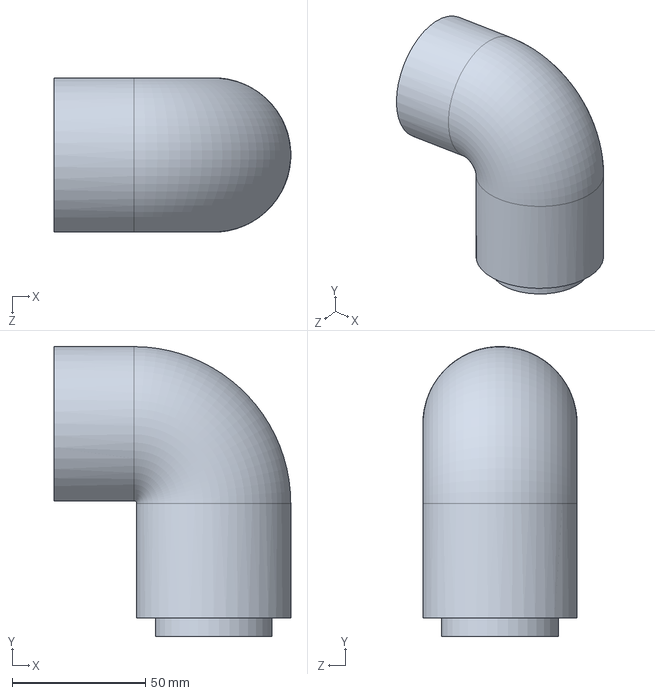
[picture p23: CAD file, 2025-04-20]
Mechanical Subsystems/Reload Tubes/joint 2.SLDPRT
89.0 x 109.0 x 58.0 mm

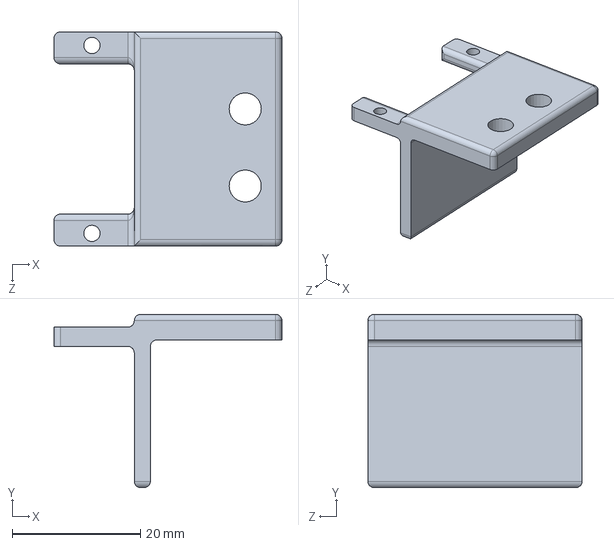
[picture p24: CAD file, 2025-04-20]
Mechanical Subsystems/SG90 servo bracket (heat sensor).SLDPRT
35.5 x 27.0 x 33.4 mm

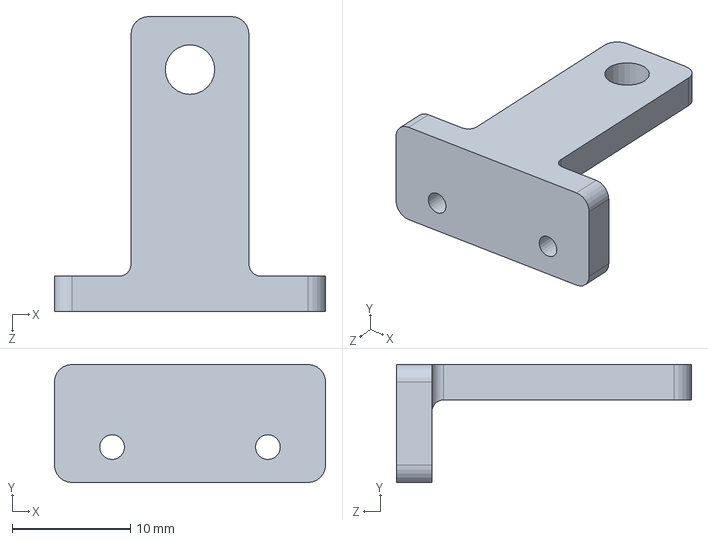
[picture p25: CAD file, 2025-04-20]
Mechanical Subsystems/AMG8833 Attachment to Servo.SLDPRT
23.0 x 10.0 x 25.0 mm

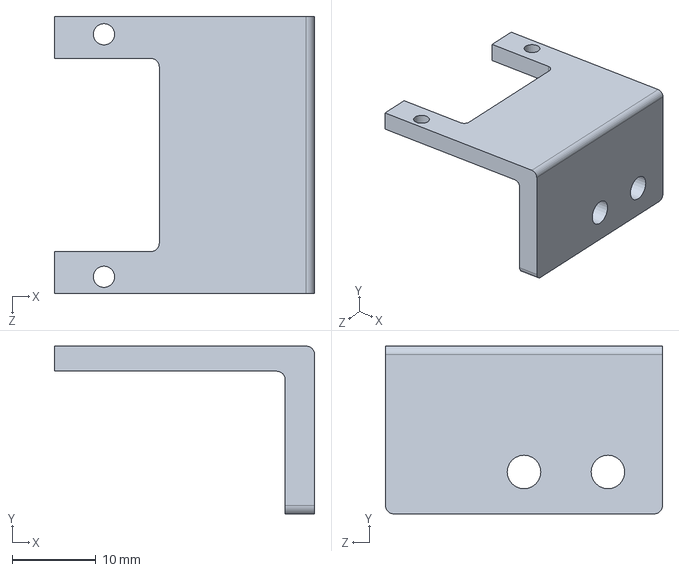
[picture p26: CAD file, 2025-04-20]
Mechanical Subsystems/Launcher/SG90 servo bracket (rack and pinion).SLDPRT
31.0 x 20.0 x 33.0 mm

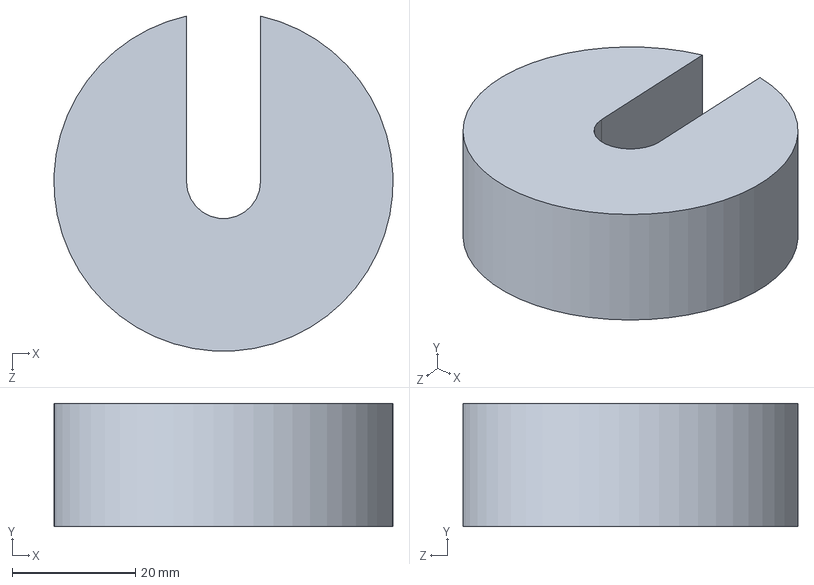
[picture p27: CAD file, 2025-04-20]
Mechanical Subsystems/200g counter-weight.SLDPRT
55.0 x 20.0 x 54.3 mm

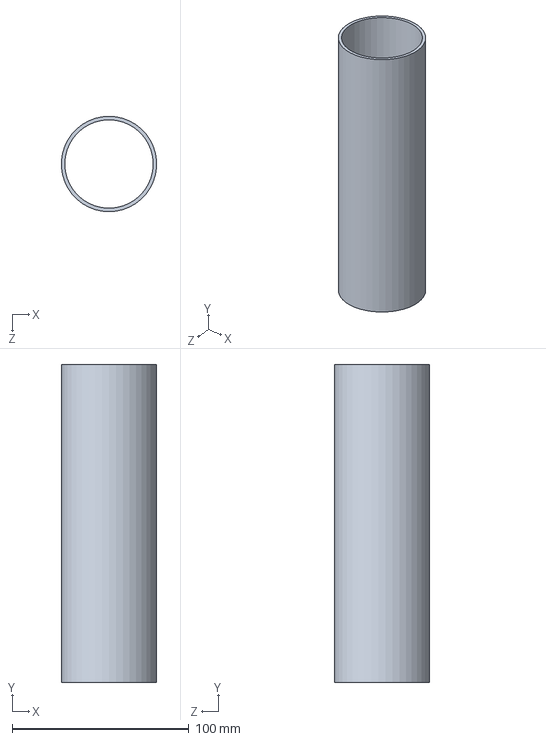
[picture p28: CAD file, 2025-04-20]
Mechanical Subsystems/Reload Tubes/tube 18cm.SLDPRT
53.8 x 180.0 x 54.0 mm

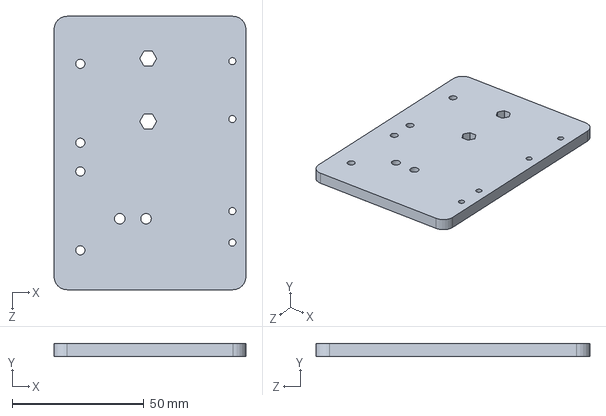
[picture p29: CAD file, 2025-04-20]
Mechanical Subsystems/Launcher/DC motor & servo platform.SLDPRT
73.0 x 5.00 x 104.0 mm

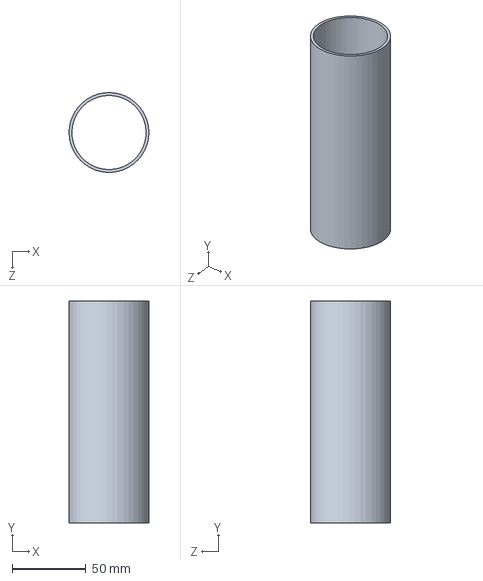
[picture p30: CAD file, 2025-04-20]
Mechanical Subsystems/Reload Tubes/tube 15cm.SLDPRT
54.0 x 150.0 x 54.0 mm

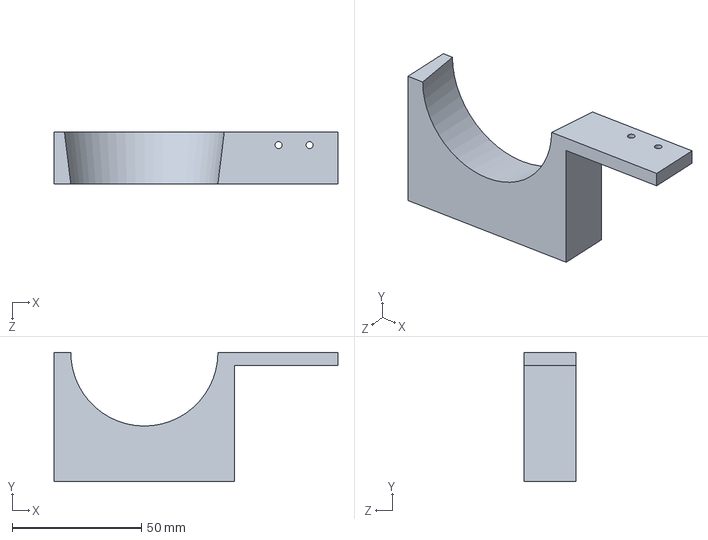
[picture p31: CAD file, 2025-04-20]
Mechanical Subsystems/Reload Tubes/tubes holder.SLDPRT
110.0 x 50.0 x 20.0 mm

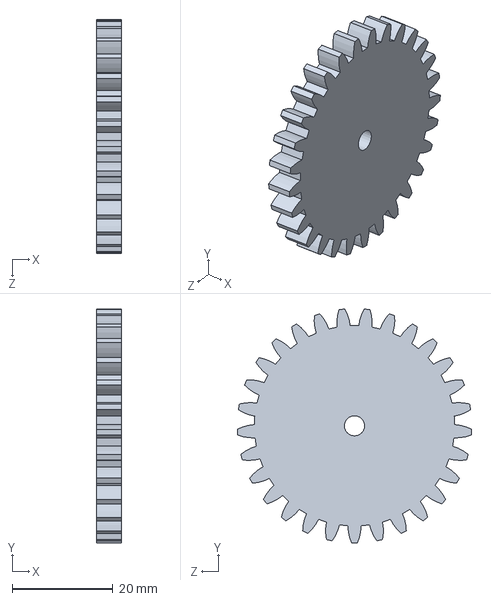
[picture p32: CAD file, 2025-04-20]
Mechanical Subsystems/Launcher/pinion gear (rack and pinion).SLDPRT
5.00 x 46.4 x 46.5 mm

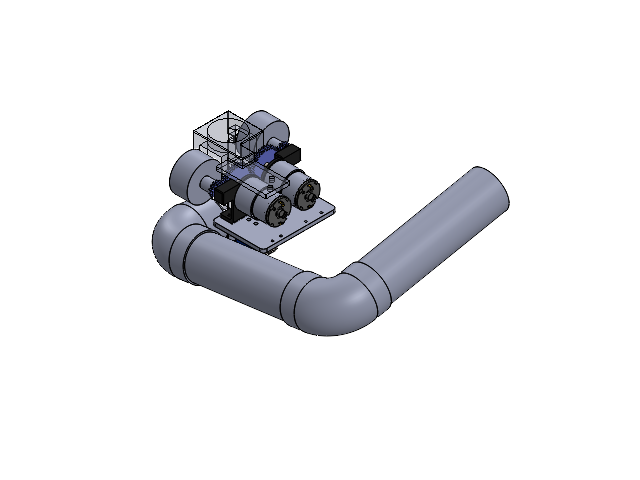
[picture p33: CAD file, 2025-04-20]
Mechanical Subsystems/Launcher/launcher + reload tubes assem.SLDASM
launcher
platform
rack spur rectangular_iso
flywheel x 2
small gear x 2
DC motor gear x 2
GEARED BODY, MOTOR, JGB37-520 x 2
DC MOTOR, JGB37-520 x 2
MOTOR SHAFT, JGB37-520 x 2
SHAFT COUPLER, JGB37-520 x 2
COUPLING BRACKET, GEARED BODY TO DC MOTOR, JGB37-520 x 2
PLASTIC COVER, DC MOTOR, JGB37-520 x 2
CONNECTION, DC MOTOR, JGB37-520 x 4
pan cross head_am x 6
MM-JGB37 bracket
tube 15cm
tube 18cm
joint
joint 2
DC motor & servo platform
MM-JGB37 bracket 2
spur gear_iso
Servo Motor
Servo Motor engrane hélice
SG90 servo bracket (rack and pinion)

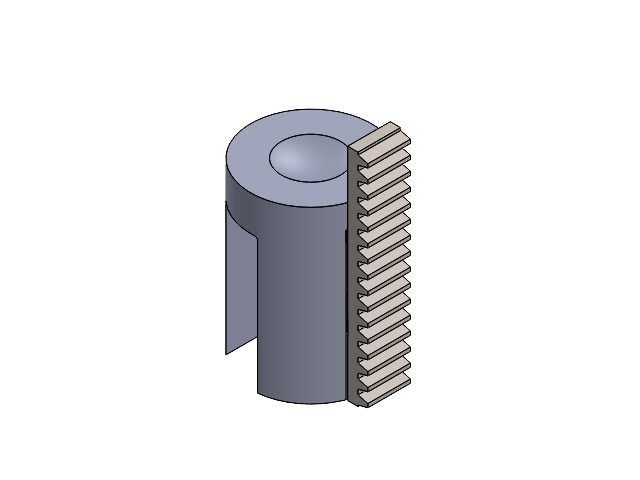
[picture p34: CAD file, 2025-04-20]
Mechanical Subsystems/Launcher/ball platform.SLDASM
platform
rack spur rectangular_iso

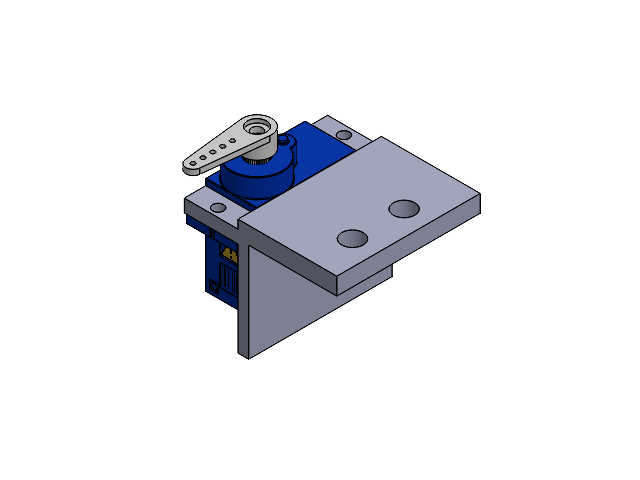
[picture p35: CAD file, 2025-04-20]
Mechanical Subsystems/SG90 servo assem (heat sensor).SLDASM
Servo Motor
Servo Motor hélice
Servo Motor engrane hélice
bracket heat

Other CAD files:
Mechanical Subsystems/Launcher/JGB37-520 right assem.SLDASM
Mechanical Subsystems/Launcher/SG90 servo assem (rack and pinion).SLDASM
Mechanical Subsystems/Launcher/flywheel.SLDASM
Mechanical Subsystems/Launcher/JGB37-520 left assem.SLDASM
Mechanical Subsystems/Launcher/DC motor gear.SLDPRT
Mechanical Subsystems/Launcher/JGB37-520 left bracket.SLDPRT
Mechanical Subsystems/Launcher/JGB37-520 right bracket.SLDPRT
Mechanical Subsystems/Launcher/launcher.SLDPRT
Mechanical Subsystems/Reload Tubes/joint.SLDPRT

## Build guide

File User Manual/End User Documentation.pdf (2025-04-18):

# End User Documentation

### Section 1: General Systems Description and Critical Data

Hardware Specifications

| List | Specifications | Notes
Turtlebot | Dimensions (mm) (LxWxH) | Turtlebot3 & Launcher: 293x262x212
| Weight (kg) | Launcher: 0.924 Turtlebot: 1.51 Counter-weight: 0.2 Total weight: 2.634
| Wheel Base (mm) | 80.66 | From center of DYNAMIXEL to the center of ball caster
| DC Motor | 2x JGB37-520
| Servo Motor | 2x SG90
Payload | Dimensions (mm) (LxWxH) | 40 x 40 x 40 | Ping Pong Ball
| Weight (kg) | Ping Pong: 0.0027 Total: 0.0243 | 9 Ping Pong Ball
System | Battery Capacity | 1800 mAh
| Expected Operating Time | 92.3 min
| Communication Interface | GPIO,PWM,I2C,UART,USB, TTL, TCP

Instructions before start of mission
1. Put the balls in the pipe.
2. Set the servo to zero angle by the test code. (Keep the rack away from the pinion during this step).
3. Place the robot inside the maze and run the scripts.
Mission flow
1. The turtlebot navigates through the maze and creates a slam map using lidar points along with frontier exploration.
2. It simultaneously looks for heat sources using the AMG8833 sensor.
3. If the temperature measured exceeds the threshold value, the balls are fired.
4. The above steps are again repeated.

### Section 2: Technical Guide

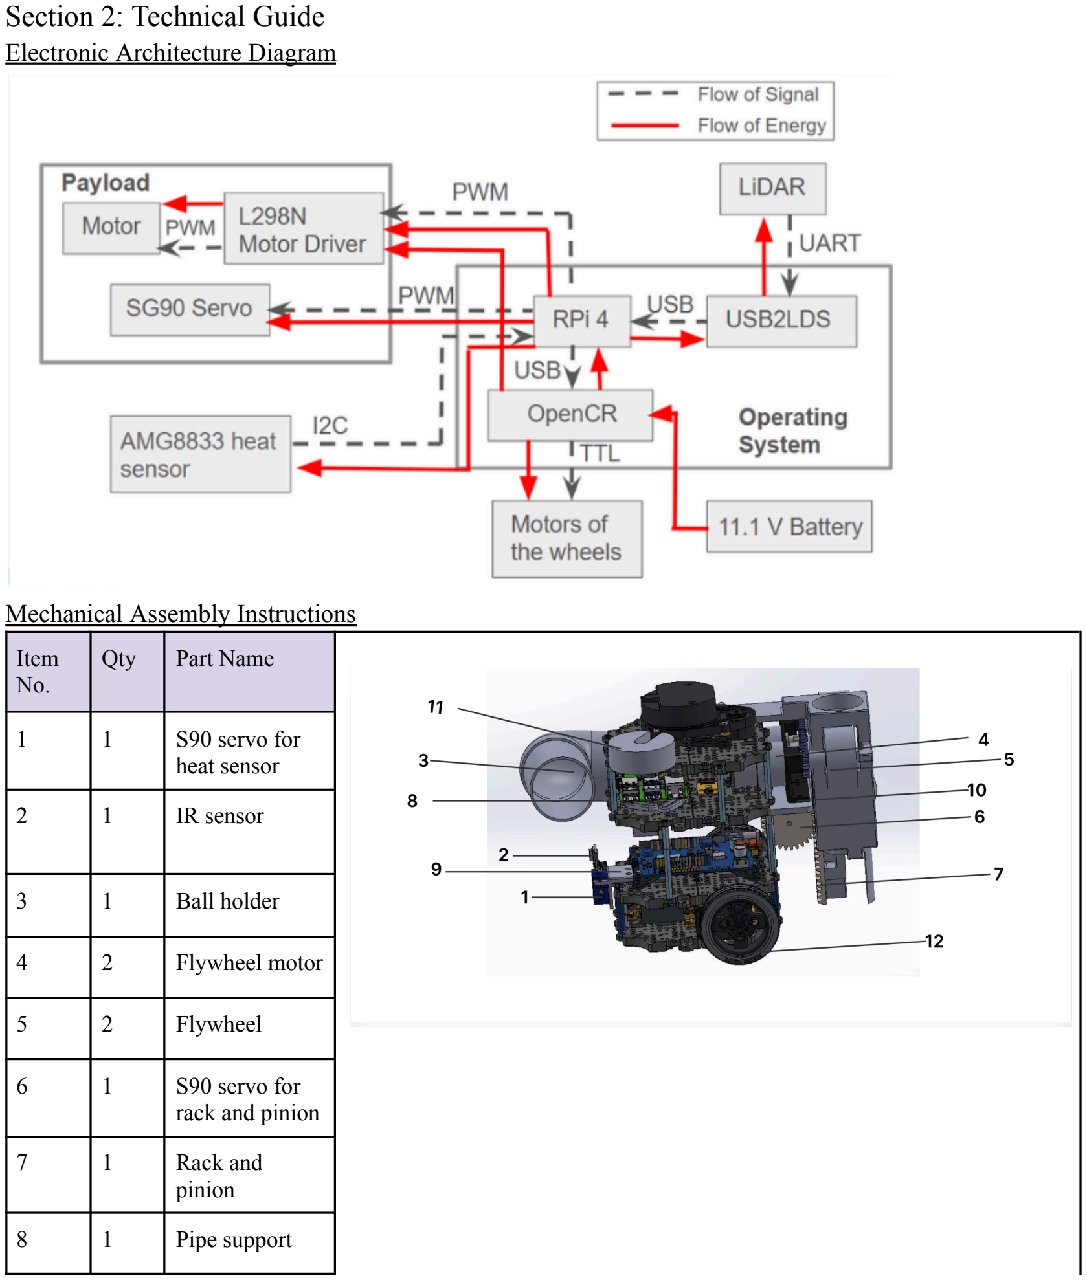
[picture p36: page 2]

Electronic Architecture Diagram

Mechanical Assembly Instructions

Item No. | Qty | Part Name
1 | 1 | S90 servo for heat sensor
2 | 1 | IR sensor
3 | 1 | Ball holder
4 | 2 | Flywheel motor
5 | 2 | Flywheel
6 | 1 | S90 servo for rack and pinion
7 | 1 | Rack and pinion
8 | 1 | Pipe support

9 | 1 | Sensor servo holder
10 | 1 | Acrylic Holder for Launcher
11 | 1 | Weight
12 | 1 | Turtlebot3 burger

### Section 3: Acceptance Defect Log

Defect | Rectification | Defect Classification
Critical | Major | Minor
The rubber grip on the flywheels may spoil over a long time. | Replace the rubber grip. | | x

### Section 4: Factory Acceptance Test

Component | To be checked | Observation
OpenCR | Able to be powered by the LiPo Battery | Green LED lights up when connected to a power source, boot up tune being played
RPi | Able to turn on the RPi when connected to OpenCR | Red light turns on while green light flashes
| Can be connected to from the remote laptop | Terminal returns “Welcome to Ubuntu…” when “ssh ubuntu@<ip-address>” is run on terminal
| RPi is able to connect to the network (Wi-Fi) | RPi appears in the hotspot’s connected devices list
LiDAR | Able to spin and collect data consistently | Environment will be mapped on Rviz with slam toolbox
SG90 (1) | Able to rotate the rack and pinion to feed payload into flywheels | Platform goes up and down launcher tube smoothly
SG90+AMG8833 sensor | Able to scan for the heat sources | The sensor prints an 8x8 array of temperature when the test code is run

JGB37-520 x2 (Flywheel motors) | Able to shoot the ball above the wall | The flywheel shoots the ball when the test code is run.
Wheels | Able to move the bot in all directions freely. | Bot can be controlled properly when running ‘rteleop’
Ball caster | Able to roll in all directions freely. | Bot able to move around in all direction smoothly with ball caster attached
Structural Stability | Structural platforms and components installed correctly | Shake Turtlebot to verify all components are mounted securely
| Verify all fasteners installed and tightened | Verify fastener count are consistent with assembly document

### Section 5: Maintenance and Part Replacement Log

Log No. | Defect Date | Qty | Defect Component | Problem Description | Rectification | Close Date
1. | 1 April 2024 | 1 | SG90 servo motor | The servo was burnt as it was supplied 5 V instead of 3.3 V | The servo motor was replaced. | 1 April 2024

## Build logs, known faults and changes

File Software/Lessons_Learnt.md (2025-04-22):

## Lessons Learnt

### **Nav2 Parameters**

We should have conducted more testing and fine-tuning of the **Nav2 stack**, particularly in terms of how the **costmap updates in real time**. During our run, the costmap update rate was too slow, which hindered the robot’s ability to quickly react to obstacles and changes in the environment.

**Potential Improvements:**

- Increase the **frequency of costmap updates**
- Expand the **`laser_scan_max_range`** parameter
- Better tune the **inflation radius** and **cost scaling factors**

These changes could have made the robot more responsive in navigating complex mazes, while creating a more accurate buffer zone around the robot to reduce the risk of collisions.

---

### **Heat Sensor Calibration**

During the actual run, the **heat sensing logic** had issues where it fired too early or could not detect the heat source **(Threshold Insensitivity)**. This revealed the need to fine-tune **heat detection thresholds** and the conditions for **triggering flare firing**.

**Suggested Action:**

- Further **calibration in a controlled environment**
- Test with various **distances and temperatures**

**Alternative Strategy:**

- **Moving average**: Average the temperature over a sliding window of frames to smooth out noise, and trigger flare firing when the temperature exceeds the average by a certain margin.

This would help achieve more reliable detections and minimize false triggers.

---

### **Servo Sweep**

Initially, the heat sensor was mounted on a **servo** to perform a **sweeping motion (180°)** to expand detection coverage. While conceptually viable, it introduced several technical issues:

- The amg sensor **frequently fell off** the servo, affecting recorded values
- **Constant turning** likely increased **noise in the readings**

---

### **Navigation Strategy**

Our initial strategy relied on **frontier-based exploration**. However, this proved inefficient in the maze we were given, causing the robot to spend excessive time in central regions and **miss heat sources placed near corners**.

**Alternative Strategies:**

- Adopt a **wall-following strategy** for better edge coverage
- Consider a **hybrid strategy**: prioritize frontiers adjacent to walls
- Use **LiDAR distance readings** to explore open areas quickly

While navigating toward larger open spaces can help collect map data efficiently, it also risks missing smaller yet important sections. A **balance must be struck** based on environment constraints and task priorities.

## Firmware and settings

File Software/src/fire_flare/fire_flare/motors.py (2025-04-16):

import rclpy
from rclpy.node import Node
from std_msgs.msg import Bool
import RPi.GPIO as GPIO
import time

# Raspberry Pi GPIO setup
GPIO.setmode(GPIO.BOARD)

FLYWHEEL = 13
ENB = 15
SERVO_PIN = 32

GPIO.setup([FLYWHEEL, ENB, SERVO_PIN], GPIO.OUT)

# Initialize PWM objects
pwm_flywheel = GPIO.PWM(ENB, 1000)
pwm_servo = GPIO.PWM(SERVO_PIN, 50)
pwm_servo.start(0)


class FlareExplorerNode(Node):
    def __init__(self):
        super().__init__('flare_explorer_node')

        # Subscriber to fire flare signal
        self.fire_sub = self.create_subscription(
            Bool, '/fire_flare', self.fire_callback, 10)

    def fire_callback(self, msg):
        if msg.data:
            self.get_logger().info("Received 'fire!' signal.")
            self._fire_flare()

    def _fire_flare(self):
        """Start flywheel, reload, and fire flare three times."""
        print("Starting Flywheel ...")
        self.start_flywheel()
        time.sleep(3)  # spin-up time

        for i in range(3):
            print(f"Firing {i+1} ...")
            self.reload()

            if i == 0:
                time.sleep(2.5)
            elif i == 1:
                time.sleep(0.5)

        print("Stopping Flywheel ...")
        self.stop_flywheel()

    def start_flywheel(self):
        pwm_flywheel.start(100)  # Full speed
        GPIO.output(FLYWHEEL, GPIO.HIGH)

    def stop_flywheel(self):
        GPIO.output(FLYWHEEL, GPIO.LOW)
        pwm_flywheel.stop()

    def reload(self):
        """Reloads by moving the servo."""
        for angle in [0, 180, 0]:
            duty = 2 + (angle / 18)
            pwm_servo.ChangeDutyCycle(duty)
            time.sleep(0.5)
        pwm_servo.ChangeDutyCycle(0)
        time.sleep(0.3)


def main(args=None):
    rclpy.init(args=args)

    flare_explorer_node = FlareExplorerNode()
    rclpy.spin(flare_explorer_node)

    # Shutdown ROS2 after the node is done
    flare_explorer_node.destroy_node()
    rclpy.shutdown()
    pwm_servo.stop()
    GPIO.cleanup()


if __name__ == '__main__':
    main()

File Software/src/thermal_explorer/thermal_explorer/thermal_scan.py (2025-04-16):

import rclpy
from rclpy.node import Node
from std_msgs.msg import Bool
from nav_msgs.msg import Odometry
from geometry_msgs.msg import Twist
import time
import busio
import board
import adafruit_amg88xx
import RPi.GPIO as GPIO
import math

def euler_from_quaternion(x, y, z, w):
    t0 = +2.0 * (w * x + y * z)
    t1 = +1.0 - 2.0 * (x * x + y * y)
    roll_x = math.atan2(t0, t1)

    t2 = +2.0 * (w * y - z * x)
    t2 = +1.0 if t2 > +1.0 else t2
    t2 = -1.0 if t2 < -1.0 else t2
    pitch_y = math.asin(t2)

    t3 = +2.0 * (w * z + x * y)
    t4 = +1.0 - 2.0 * (y * y + z * z)
    yaw_z = math.atan2(t3, t4)

    return roll_x, pitch_y, yaw_z

class ThermalDetectorNode(Node):
    def __init__(self):
        super().__init__('thermal_detector')

        self.publisher_ = self.create_publisher(Bool, '/fire_flare', 10)
        self.cmd_vel_pub = self.create_publisher(Twist, '/cmd_vel', 10)
        self.odom_subscription = self.create_subscription(
            Odometry,
            '/odom',
            self.odom_callback,
            10
        )

        self.THRESHOLD = 27.0  # Celsius
        self.MAX_TEMP_TRIGGER = 29.5  # Celsius
        self.detected_locations = []
        self.detected_count = 0
        self.current_position = (0.0, 0.0)
        self.current_yaw = 0.0
        self.detecting = True

        # Set up I2C and thermal sensor
        i2c_bus = busio.I2C(board.SCL, board.SDA)
        self.sensor = adafruit_amg88xx.AMG88XX(i2c_bus)

        # Set up GPIO and servo motor
        self.servo_pin = 13
        GPIO.setmode(GPIO.BCM)
        GPIO.setup(self.servo_pin, GPIO.OUT)
        self.pwm = GPIO.PWM(self.servo_pin, 50)  # 50 Hz
        self.pwm.start(0)

        # Timer to perform sweep and detection every second
        self.timer = self.create_timer(1.0, self.sweep_and_detect)

    def angle_to_duty_cycle(self, angle):
        return 2.5 + (angle / 180.0) * 10.0

    def odom_callback(self, msg):
        position = msg.pose.pose.position
        orientation = msg.pose.pose.orientation
        self.current_position = (position.x, position.y)
        _, _, self.current_yaw = euler_from_quaternion(
            orientation.x, orientation.y, orientation.z, orientation.w)

    def is_near_existing_source(self, x, y, threshold=0.5):
        for px, py in self.detected_locations:
            if math.sqrt((x - px) ** 2 + (y - py) ** 2) < threshold:
                return True
        return False

    def move_forward_safely(self, max_duration=5.0):
        twist = Twist()
        speed = 0.03  # slower forward speed
        twist.linear.x = speed
        start_time = self.get_clock().now().seconds_nanoseconds()[0]

        self.cmd_vel_pub.publish(twist)

        while rclpy.ok():
            current_time = self.get_clock().now().seconds_nanoseconds()[0]
            if current_time - start_time >= max_duration:
                break

            pixel_array = self.sensor.pixels
            high_temp_count = sum(1 for row in pixel_array for temp in row if temp > 30.0)

            if high_temp_count > 10:
                self.get_logger().info(f"Too hot ahead: {high_temp_count} pixels > 30°C. Stopping.")
                break

            time.sleep(0.1)

        # Stop the robot
        twist.linear.x = 0.0
        self.cmd_vel_pub.publish(twist)

    def sweep_and_detect(self):
        if not self.detecting:
            return

        pixel_array = self.sensor.pixels

        self.get_logger().info("Thermal array:")
        for row in pixel_array:
            self.get_logger().info(str(["{:.1f}".format(temp) for temp in row]))

        count = sum(1 for row in pixel_array for temp in row if temp > self.THRESHOLD)
        max_temp = max(max(row) for row in pixel_array)
        self.get_logger().info(f"Max temperature detected: {max_temp:.1f}°C")

        x, y = self.current_position

        if max_temp > self.MAX_TEMP_TRIGGER and not self.is_near_existing_source(x, y):
            self.get_logger().info(f"Max temp {max_temp:.1f} > {self.MAX_TEMP_TRIGGER}, firing and moving...")

            # Log location to prevent duplicate triggering
            self.detected_locations.append((x, y))
            self.detected_count += 1

            # Fire flare once
            msg = Bool()
            msg.data = True
            self.publisher_.publish(msg)

            # Move forward carefully
            self.move_forward_safely()

            if self.detected_count >= 2:
                self.get_logger().info("Detected 2 distinct sources. Stopping detection.")
                self.cleanup()
                self.detecting = False

        elif count > 2 and not self.is_near_existing_source(x, y):
            self.get_logger().info(f'Heat source detected at ({x:.2f}, {y:.2f})')
            self.detected_locations.append((x, y))
            self.detected_count += 1

            msg = Bool()
            msg.data = True
            self.publisher_.publish(msg)

            if self.detected_count >= 2:
                self.get_logger().info("Detected 2 distinct sources. Stopping detection.")
                self.cleanup()
                self.detecting = False

    def cleanup(self):
        self.pwm.ChangeDutyCycle(0)
        time.sleep(0.5)
        self.pwm.stop()
        GPIO.cleanup()
        self.get_logger().info("GPIO and PWM cleaned up.")

def main(args=None):
    rclpy.init(args=args)
    node = ThermalDetectorNode()
    rclpy.spin(node)
    rclpy.shutdown()

if __name__ == '__main__':
    main()

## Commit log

2025-03-18 motor test code
2025-03-20 AMG8833 I2C with Raspi Code
2025-03-20 Servo + AMG8833 Sweep
2025-04-17 Create Power_Budget_Calculation
2025-04-17 Update Power_Budget_Calculation
2025-04-20 Create Turtlebot Assembly Files
2025-04-21 Rename Mechanical Subsystems/200g counter-weight.SLDPRT to Mechanical Subsystems/CAD files/200g counter-weight.SLDPRT
    [200g counter-weight.SLDPRT]
2025-04-21 Rename Mechanical Subsystems/CAD files/200g counter-weight.SLDPRT to Mechanical Subsystems/200g counter-weight.SLDPRT
    [200g counter-weight.SLDPRT]
2025-04-22 Update and rename Power_Budget_Calculation to Power_Budget_Calculation.md
2025-04-23 Update Turtlebot Assembly Files
